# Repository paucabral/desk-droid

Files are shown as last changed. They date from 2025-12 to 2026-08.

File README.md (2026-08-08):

# DeskDroid




> A compact, autonomous ESP32-S3 desktop companion robot featuring expressive OLED eyes, environmental telemetry, capacitive gesture controls, and a local web dashboard interface.

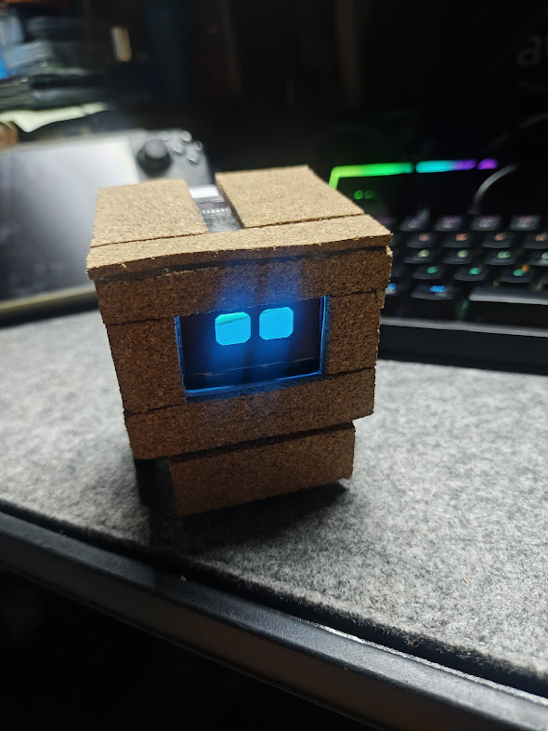
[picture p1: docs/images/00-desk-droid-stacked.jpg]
stacked


## Preview

This build uses PVC boards and Cork Sheets for the chassis, and pogo pin magnets for split chassis connectivity between the standalone base and the motor chassis.
| Parts | Preview |
| :--- | :--- |
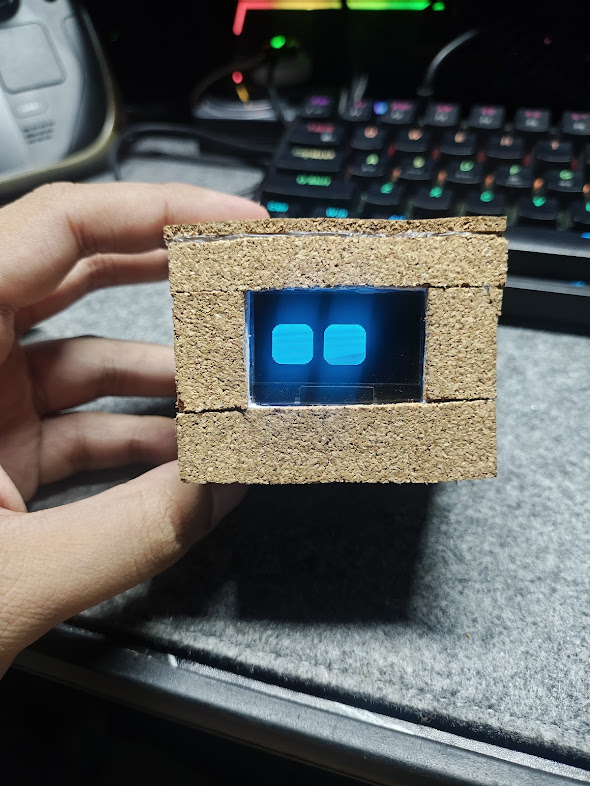
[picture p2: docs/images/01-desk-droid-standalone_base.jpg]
Standalone Base
| Standalone Base |  |
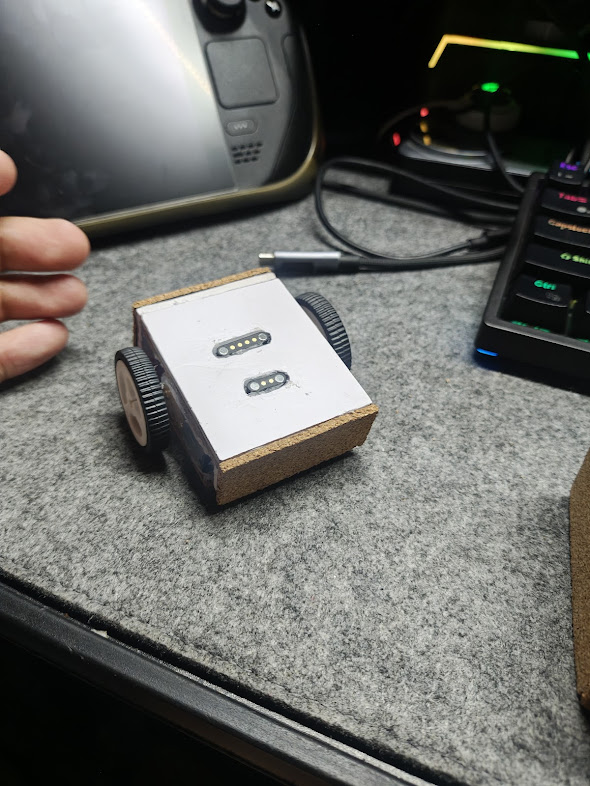
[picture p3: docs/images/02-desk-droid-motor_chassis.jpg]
Motor Chassis
| Motor Chassis |  |
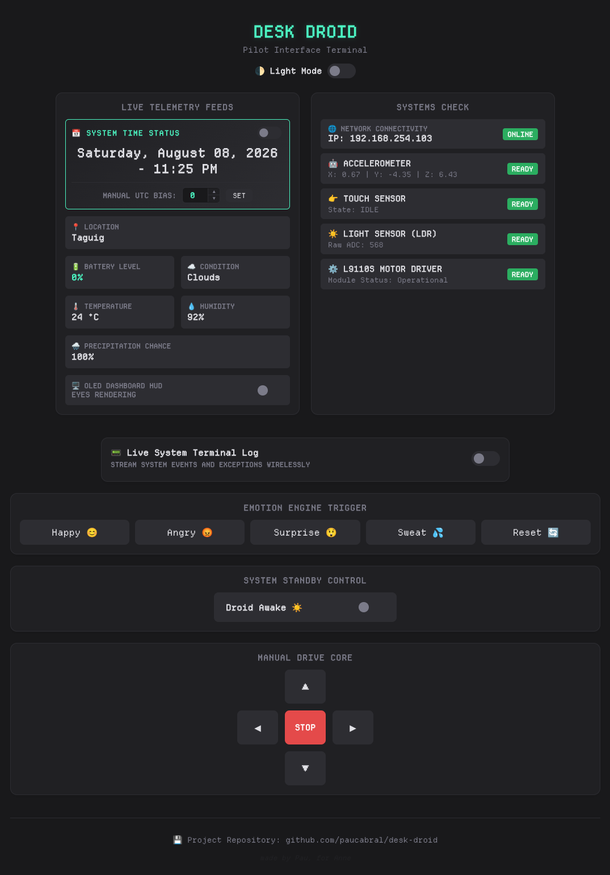
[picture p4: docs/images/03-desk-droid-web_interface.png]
Web Interface
| Web Interface |  |

## Key Features
- Expressive Eye Animations: Dynamic emotional states (Happy, Angry, Confused, Sweating, Tired) powered by FluxGarage_RoboEyes on a 1.3" OLED display.
- Interactive Touch Gestures: Single-point capacitive touch interface supporting multi-tier hold duration triggers (Happy reaction, Angry reaction, Dashboard overlay, and Deep Sleep power management).
- Local Web Dashboard & Remote Control: Built-in HTTP server hosting a responsive dashboard to drive locomotion, force emotional states, toggle military/standard time, view live sensor telemetry, and read streaming serial logs.
- Environmental & Motion Awareness:
  - ADXL345 Accelerometer: High-G shake detection and physics reaction loops.
  - TEMT600 Light Sensor: Ambient light detection for automatic screen dimming and night sleep mode.
  - OpenWeather API & NTP Synchronization: Automatic location, weather condition, temperature, humidity, and clock updates via Wi-Fi.
- Autonomous and Manual Navigation: Idle motion loops and manual navigation through the web dashboard when connected to the optional motor chassis.

## Parts and Dependencies

### 💿 Software
1. **Development Environment:** [Visual Studio Code](https://code.visualstudio.com/) with [PlatformIO](https://platformio.org/) Extension installed.
2. **Core Libraries:** (as seen in [lib/README.md](lib/README.md)):
    - Adafruit_GFX & Adafruit_SH110X (Display Driver)
    - Adafruit_ADXL345_U & Adafruit_Sensor (Accelerometer)
    - FluxGarage_RoboEyes (Eye Animations)
    - CuteBuzzerSounds (Audio Effects)
    - WiFiManager (Captive Portal Provisioning)
    - ArduinoJson (Web Telemetry Parsing)
3. **Cloud Services:** [OpenWeather API Key](https://openweathermap.org/api) (Free Tier)

### ⚙️ Hardware

| Category | Component | Specification |
| :--- | :--- | :--- |
| **Microcontroller** | ESP32-S3 SuperMini | Dual-core 240MHz, 2.4GHz Wi-Fi |
| **Display** | 1.3" OLED Display | SH1106G I2C (128x64 resolution) |
| **Sensors** | TEMT600 | Ambient Light Sensor |
| | ADXL345 | 3-Axis Digital Accelerometer |
| | TTP223 | Capacitive Touch Module |
| **Actuators** | G12 N20 DC Motors (Right Angled) | Dual Gear Motors w/ L9110S Driver |
| | Piezo Buzzer | Passive Buzzer for audio cues |
| **Power** | 3.7V LiPo Battery | Single-cell rechargeable battery |

## Project Structure
```
desk-droid/
├── fritzing/              # Circuit schematics and component models
│   ├── parts/             # Custom Fritzing component definitions
│   └── desk-droid.fzz     # Main project circuit schematic
├── include/               # System C++ header interfaces
│   ├── audio_system.h     # Audio player & buzzer API header
│   ├── config.h           # Hardware pinout & system threshold constants
│   ├── display_ui.h       # OLED screen & dashboard drawer functions
│   ├── motors.h           # L9110S motor direction state declarations
│   ├── network_system.h   # Web server, telemetry & API endpoints
│   └── power_system.h     # Power telemetry & deep sleep interface
├── lib/                   # Project dependencies & vendor libraries
│   ├── CuteBuzzerSounds/  # Passive buzzer sound effects library
│   └── RoboEyes/          # FluxGarage RoboEyes display animation engine
├── src/                   # Core software implementation
│   ├── audio_system.cpp   # Audio hardware routines
│   ├── dashboard.html     # Single-file Web UI dashboard (HTML/CSS/JS)
│   ├── display_ui.cpp     # OLED UI graphics rendering engine
│   ├── main.cpp           # Main lifecycle setup(), loop() & event handlers
│   ├── motors.cpp         # L9110S motor driver hardware implementations
│   ├── network_system.cpp # Web server routes & OpenWeather API fetchers
│   └── power_system.cpp   # Power telemetry & deep sleep implementation
├── platformio.ini         # PlatformIO build environment configuration
├── secrets.ini            # Private credentials file (Git ignored)
└── secrets.ini.example    # Configuration template for secrets
```

Note: `README.md` files in each directory for further details.

## Usage

### 🤖 Schematics
Follow the schematics as seen in [fritzing/desk-droid.fzz](fritzing/desk-droid.fzz). Use [Fritzing](https://fritzing.org/) and follow the instructions at [fritzing/README.md](fritzing/README.md) to import the parts.

### 🌐 Code: Building & Uploading
1. Clone the repository and open in VScode with PlatformIO extension installed.
2. Import the PlatformIO libraries listed in [lib/README.md](lib/README.md).
3. Create a `secrets.ini` file using [secrets.ini.example](secrets.ini.example) as reference, and place your [OpenWeather API key](https://openweathermap.org/api).
    ```ini
    [secrets]
    OPENWEATHER_API_KEY = your_openweather_api_key_here
    ```
4. Connect the microcontroller and select the proper port.
5. **Build** then **Upload** the project.

### 🛜 Initial Wi-Fi Setup
On first boot (or if saved Wi-Fi is unavailable), DeskDroid will create a Wi-Fi Access Point named Desk-Droid-Setup. Connect to this network on your smartphone or PC to enter your local Wi-Fi credentials via the captive portal. Once connected, DeskDroid will acquire an IP address and display it on-screen.

### 🎮 Interactive Controls & Touch Gestures

DeskDroid uses time-based hold durations on the **TTP223 Touch Sensor** to navigate modes:

| Duration | Action | Response |
| :--- | :--- | :--- |
| **0.3s – 0.9s** | Short Tap | **Happy Reaction:** Laugh animation, sound effect, and brief forward scoot. |
| **1.0s – 1.8s** | Medium Hold | **Angry Reaction:** Angry eyes, sound effect, and brief backward scoot. |
| **1.8s** | Long Hold | **Dashboard Toggle:** Opens environmental metrics & system status overlay. |
| **3.0s+** | Sustained Press | **Deep Sleep:** Plays shutdown chime, powers off OLED, and enters low-power sleep. |

### 🌐 Web Dashboard
Access the DeskDroid web control interface by navigating to http://<DROID_IP_ADDRESS> in any web browser. The following API endpoints are also available:
- /drive?dir=[forward|backward|left|right|stop]: Manual drive overrides.
- /emotion?type=[happy|angry|confused|sweat|default]: Force specific emotional animations.
- /telemetry: Fetches JSON data for battery, weather, location, time, and system states.
- /serial_data: Real-time web terminal stream for debugging logs without a USB connection.

## 🤖 AI Usage & Transparency Disclaimer
This repository was developed with assistance from Large Language Model (LLM) AI tools acting as a collaborative coding partner.
- Code Refactoring & Optimization: AI was used for low-level I2C multiplexing routines, non-blocking timer loops, and debugging embedded power/brownout issues.
- Documentation & Web Assets: Project documentation, README.md structural formatting, and initial HTML/CSS dashboard layouts were generated or refined using AI prompts.
- Hardware Validation: All electronic circuits, PCB component choices, physical pin allocations, and assembly were manually constructed, tested, and verified on physical hardware by the author.

---

*DeskDroid: Made by Pau, for Anne*

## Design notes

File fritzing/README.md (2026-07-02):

### Fritzing Files

This directory is intended for [Fritzing](https://fritzing.org/) parts and project files.

### Parts
Parts list directory (as imported in this repository):
- **ESP32-S3 SuperMini**
    - [💬 Forum Link](https://forum.fritzing.org/t/part-request-esp32-s3-supermini/22633/3)
    - [💾 Direct Download](https://forum.fritzing.org/uploads/short-url/of9Geqh2JwUCkv0tIVA6ZAqvkB.fzpz)
- **1.3 inch OLED 128x64 I2C**
    - [💬 Forum Link](https://forum.fritzing.org/t/oled-128x64-i2c-monochrome-display-ssd1306-created/1202)
    - [💾 Direct Download](https://forum.fritzing.org/uploads/default/original/1X/72f402789483e5047e79393485ef8bd9f9c0cb51.fzpz)
- **Passive Buzzer**
    - [💬 Forum Link](https://forum.fritzing.org/t/where-to-find-small-buzzer-in-fritzing/4843/3)
    - [💾 Direct Download](https://forum.fritzing.org/uploads/short-url/4nW0Ru7nvFcOlm5PVc3IXuMKVPB.fzpz)
- **Capacitive Touch Sensor**
    - [💬 Forum Link](https://forum.fritzing.org/t/ttp223b-module-alternative-design/11139/2)
    - [💾 Direct Download](https://forum.fritzing.org/uploads/short-url/6EryNAQ6wU4tDFa4MLlj1lODkUe.fzpz)
- **DHT11 Temperature and Humidity Sensor**
    - [💬 Forum Link](https://arduinomodules.info/download/ky-015-temperature-humidity-sensor-module-zip-file/)
    - [💾 Direct Download](https://arduinomodules.info/download/ky-015-temperature-humidity-sensor-module-zip-file/#unlock)
- **TEMT6000 Light Sensor**
    - [💬 Forum Link](https://forum.fritzing.org/t/temt6000-brick-download/20406/2)
    - [💾 Direct Download](https://forum.fritzing.org/uploads/short-url/kp9lpQa11v5nO44Q2Xz5W5kLW1z.fzpz)
- **MQ-135 Air Quality Sensor**
    - [💬 Forum Link](https://forum.fritzing.org/t/mq-135-gas-sensor-breakout-board/26152)
    - [💾 Direct Download](https://forum.fritzing.org/uploads/short-url/6SuZ75KSibpSUzOyTHRWeNgN6u2.fzpz)
**ADXL345 Accelerometer**
    - [💬 Forum Link](https://github.com/adafruit/Fritzing-Library/blob/master/parts/Adafruit%20ADXL345.fzpz)
    - [💾 Direct Download](blob:https://github.com/917bed7e-a063-43b2-9dba-4fa6b69fdde6)
**L9110 Motor Driver**
    - [💬 Forum Link](https://forum.fritzing.org/t/l9110-h-bridge-module/3110)
    - [💾 Direct Download](https://forum.fritzing.org/uploads/default/original/2X/4/487de66e80684795570d9a0d627331bf5953f003.fzpz)
**N20 Geared Motor**
    - [💬 Forum Link](https://forum.fritzing.org/t/anyone-got-an-n20-geared-mini-motor-fritzing-part/10380/11)
    - [💾 Direct Download](https://forum.fritzing.org/uploads/short-url/jln51m9ZQEeF1leAfTUMDkc4lj8.fzpz)

<!-- Template -->
<!-- **Part**
    - [💬 Forum Link]()
    - [💾 Direct Download]() -->

### Usage
1. Create a new bin named `desk-droid` inside inside Fritzing.
2. Import the parts inside the [parts/](parts/) library in the newly created `desk-droid` bin.
3. Open the `desk-droid.fzz` project.

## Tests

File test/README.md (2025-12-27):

# Tests

This directory is intended for PlatformIO Test Runner and project tests.

Unit Testing is a software testing method by which individual units of
source code, sets of one or more MCU program modules together with associated
control data, usage procedures, and operating procedures, are tested to
determine whether they are fit for use. Unit testing finds problems early
in the development cycle.

More information about PlatformIO Unit Testing:
- https://docs.platformio.org/en/latest/advanced/unit-testing/index.html

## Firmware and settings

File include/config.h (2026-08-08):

#pragma once

// OLED CONFIGURATION
#define OLED_I2C_ADDRESS        0x3c
#define OLED_SCL                13
#define OLED_SDA                12
#define OLED_SCREEN_WIDTH       128 
#define OLED_SCREEN_HEIGHT      64 
#define OLED_RESET              -1   

// BUZZER PIN
#define BUZZER_PIN              11

// TOUCH SENSOR PIN
#define TOUCH_PIN               10

// LIGHT SENSOR (LDR) CONFIGURATION
#define LDR_PIN                 8
#define LDR_THRESHOLD           200 

// ACCELEROMETER CONFIGURATION
#define ACCEL_SCL               7
#define ACCEL_SDA               6
#define SHAKE_THRESHOLD         15.0

// MOTOR CONFIGURATION (Dual H-Bridge e.g., L9110S / L298N)
#define MOTOR_IA1               3  // Left Motor Forward Control
#define MOTOR_IB1               2  // Left Motor Backward Control
#define MOTOR_IA2               5  // Right Motor Forward Control
#define MOTOR_IB2               4  // Right Motor Backward Control
#define MOTOR_MOVE_DURATION_MIN 250  // Minimum Interval between motor movements (in milliseconds)
#define MOTOR_MOVE_DURATION_MAX 500  // Maximum Interval between motor movements (in milliseconds)
#define MOTOR_MOVE_INTERVAL_MIN 5000  // Minimum Interval between motor movements (in milliseconds)
#define MOTOR_MOVE_INTERVAL_MAX 10000  // Maximum Interval between motor movements (in milliseconds)

// WIFI PORTAL CONFIGURATION
#define WIFI_AP_NAME             "Desk-Droid-Setup"
#define WIFI_CONNECT_TIMEOUT_SEC 10  // Seconds to try connecting to saved home Wi-Fi
#define WIFI_PORTAL_TIMEOUT_SEC  60  // Seconds the hotspot stays active before skipping to offline mode

// DASHBOARD CONFIGURATION
#define DASHBOARD_DURATION_MS    8000

// EVENT TRIGGERTS
#define TRIGGER_HAPPY_HOLD_MS    300   // 0.3s to 0.9s  = Happy
#define TRIGGER_ANGRY_HOLD_MS    1000  // 1.0s to 1.8s  = Angry
#define TRIGGER_DASHBOARD_MS     1800  // 1.8s          = Dashboard Opens
#define TRIGGER_SLEEP_MS         3000  // 3.0s          = Deep Sleep (Only 1.2s after Dashboard!)
#define DEBOUNCE_DELAY_MS        600   // 600ms dropout tolerance

// LIVE API CONFIGURATION
#define WEATHER_UPDATE_INTERVAL   900000  // Refresh every 15 minutes (in milliseconds)

// SHUTDOWN & SLEEP TRIGGERS
#define FREE_BATTERY_PIN         1     // Change this to your 1 remaining physical GPIO pin index!
#define TRIGGER_SLEEP_MS         10000  // Holding the touch pad for 10 full seconds triggers "Shutdown" Mode

// ADC CALIBRATION PROPERTIES
#define ADC_VREF_VOLTAGE         3.3   // ESP32-S3 internal operating logic voltage reference cap

// DYNAMIC SWEAT EMOTION CONFIGURATION
#define SWEAT_TEMP_THRESHOLD_C   30    // Temperature threshold to trigger sweat (Celsius)
#define SWEAT_ANIM_DURATION_MS   2000  // Duration of the brief transitional sweat animation (in ms)

// ─── LOCAL TIME CORE CONFIGURATION ───
#define DEFAULT_MILITARY_TIME    false  // Set to true for 24-Hour (19:25), false for 12-Hour (07:25 PM)
#define DEFAULT_TIMEZONE_OFFSET  28800
#define NTP_SERVER               "pool.ntp.org"

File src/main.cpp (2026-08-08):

#include <SPI.h>
#include <Wire.h>
#include <time.h>
#include <Adafruit_GFX.h>
#include <Adafruit_SH110X.h>
#include <Adafruit_Sensor.h>
#include <Adafruit_ADXL345_U.h>

#include <CuteBuzzerSounds.h>
#undef debug 

#include <WiFiManager.h> 
#include <ArduinoJson.h> 

// Modular System Interfaces
#include "config.h"
#include "display_ui.h"
#include "motors.h"
#include "audio_system.h"
#include "network_system.h"
#include "power_system.h"

#include "soc/soc.h"
#include "soc/rtc_cntl_reg.h"

// Instantiate Global Hardware Objects
Adafruit_SH1106G display = Adafruit_SH1106G(OLED_SCREEN_WIDTH, OLED_SCREEN_HEIGHT, &Wire1, OLED_RESET);
Adafruit_ADXL345_Unified accel = Adafruit_ADXL345_Unified(12345);

#undef DEFAULT 
#include <FluxGarage_RoboEyes.h>
RoboEyes<Adafruit_SH1106G> roboEyes(display); 

// Global Timers
unsigned long env_timer;           
unsigned long idle_timer;          
unsigned long next_idle_interval;  
unsigned long motor_stop_time = 0; 
unsigned long weather_timer = 0;   
unsigned long accel_timer = 0;

// Gesture & Page Management Timers
unsigned long touch_start_time = 0;
unsigned long dashboard_timeout = 0; 
unsigned long sweat_timeout = 0;     

// Global Web UI Intercept System Flags
bool web_control_active = false;
unsigned long web_mode_timeout = 0;
bool robot_sleeping = false;          

// Global States
float last_x = 0, last_y = 0, last_z = 0;
bool motor_running = false;
bool showing_dashboard = false;    
bool showing_pre_sweat = false;    
bool showing_post_sweat = false;   
bool accel_available = false;

// Live API Dynamic Data Registries
String live_location = "UNKNOWN";
String live_condition = "WAITING...";
String live_time_short = "--:--";
String live_time_long = "LOADING...";
bool live_use_military_time = DEFAULT_MILITARY_TIME;
int live_hour_offset = 0;
long live_timezone_offset_sec = DEFAULT_TIMEZONE_OFFSET;
int live_temp = 0;
int live_humidity = 0;
int live_rain_chance = 0;

// Dynamic Fuel Gauge Variable
int live_battery_percentage = 100;

// Raw Sensor Hardware Data Registries ---
int live_light_level = 0;
float live_accel_x = 0.0;
float live_accel_y = 0.0;
float live_accel_z = 0.0;
bool live_touch_active = false;

// --- LINKER INTEGRATION HOOK ---
// Connects the dual-channel USB/Web serial logger from network_system.cpp
extern void logTerminal(String msg);

void playEyeShutdownAnimation() {
  roboEyes.setMood(DEFAULT); roboEyes.close(); roboEyes.setPosition(S);
  unsigned long anim_start = millis();
  while (millis() - anim_start < 1000) { roboEyes.update(); delay(15); }
}

// Emotion matrix interface bridge execution vector for remote HTTP client requests
void forceWebEmotion(String type) {
  if (type == "happy") { 
    showing_pre_sweat = false; showing_post_sweat = false; roboEyes.setSweat(OFF);
    roboEyes.setMood(HAPPY); roboEyes.anim_laugh(); playSoundAsync(S_SUPER_HAPPY); 
  }
  else if (type == "angry") { 
    showing_pre_sweat = false; showing_post_sweat = false; roboEyes.setSweat(OFF);
    roboEyes.setMood(ANGRY); playSoundAsync(S_OHOOH); 
  }
  else if (type == "confused") { 
    showing_pre_sweat = false; showing_post_sweat = false; roboEyes.setSweat(OFF);
    roboEyes.setMood(TIRED); roboEyes.anim_confused(); playSoundAsync(S_SURPRISE); 
  }
  else if (type == "sweat") { 
    // Route web sweat straight to post-sweat state layout.
    // This runs the full animation sequence, but bypasses opening the OLED dashboard!
    showing_pre_sweat = false;
    showing_post_sweat = true; 
    sweat_timeout = millis() + SWEAT_ANIM_DURATION_MS; 
    roboEyes.setMood(TIRED); 
    roboEyes.setSweat(ON); 
    playSoundAsync(S_CUDDLY);
  }
  else { 
    showing_pre_sweat = false; showing_post_sweat = false; roboEyes.setSweat(OFF);
    roboEyes.setMood(DEFAULT); roboEyes.setPosition(DEFAULT); 
  }
}

void updateTimeStrings() {
  struct tm timeinfo;
  if (getLocalTime(&timeinfo)) {
    char bufShort[32];
    char bufLong[64];
    
    if (live_use_military_time) {
      strftime(bufShort, sizeof(bufShort), "%H:%M %m/%d", &timeinfo);         // "19:49 07/04"
      strftime(bufLong, sizeof(bufLong), "%A, %B %d, %Y - %H:%M", &timeinfo);   // "Saturday, July 04, 2026 - 19:49"
    } else {
      strftime(bufShort, sizeof(bufShort), "%I:%M%p %m/%d", &timeinfo);       // "07:49PM 07/04"
      strftime(bufLong, sizeof(bufLong), "%A, %B %d, %Y - %I:%M %p", &timeinfo); // "Saturday, July 04, 2026 - 07:49 PM"
    }
    live_time_short = String(bufShort);
    live_time_long = String(bufLong);
  } else {
    live_time_short = "SYNCING";
    live_time_long = "CONNECTING TO TIME POOL SERVER...";
  }
}

void setup() {
  // ─── DISABLE BROWNOUT DETECTOR AT BOOT ───
  WRITE_PERI_REG(RTC_CNTL_BROWN_OUT_REG, 0);

  initMotors();

  // Divert early boot tracking messages through the unified logging portal
  logTerminal(F("=== DROID OS BOOTING ==="));
  delay(1000); 

  Wire1.begin(OLED_SDA, OLED_SCL);
  display.begin(OLED_I2C_ADDRESS, true);
  drawChecklist(" ", " ", " ", " ", " ", "INITIALIZING...");
  delay(800); 

  Wire.begin(ACCEL_SDA, ACCEL_SCL);
  if(!accel.begin()) {
    drawChecklist("X", " ", " ", " ", " ", "ACCEL BYPASSED");
    accel_available = false; delay(1500);
  } else {
    accel.setRange(ADXL345_RANGE_4_G);
    drawChecklist("*", " ", " ", " ", " ", "   TESTING...");
    accel_available = true; delay(500);
  }

  pinMode(TOUCH_PIN, INPUT);
  drawChecklist("*", "*", " ", " ", " ", "   TESTING..."); delay(500);
  pinMode(LDR_PIN, INPUT);
  drawChecklist("*", "*", "*", " ", " ", "   TESTING..."); delay(500);
  cute.init(BUZZER_PIN);
  drawChecklist("*", "*", "*", "*", " ", "   TESTING..."); delay(500);

  initAudioSystem();
  drawChecklist("*", "*", "*", "*", "*", "       READY!");
  cute.play(S_CONNECTION); delay(1000); 

  drawWifiScreen("NETWORK CHECK", "SEARCHING...", "Checking memory for\nsaved network connections");
  
  WiFiManager wm;
  wm.setAPCallback(configModeCallback);
  wm.setConnectTimeout(WIFI_CONNECT_TIMEOUT_SEC); 
  wm.setConfigPortalTimeout(WIFI_PORTAL_TIMEOUT_SEC);

  if (wm.autoConnect(WIFI_AP_NAME)) {
    WiFi.setTxPower(WIFI_POWER_11dBm); // Cuts peak current spike significantly!

    String ipMsg = "IP: " + WiFi.localIP().toString();
    drawWifiScreen("NETWORK CHECK", "ONLINE [OK]", ipMsg.c_str());
    live_location = "LOCALIZING..."; 
    // Initialize native OS clock to UTC+8 layout instantly before hitting APIs
    configTime(live_timezone_offset_sec, 0, NTP_SERVER);
    fetchLocationAndWeather(); 
    initWebServer();
  } else {
    drawWifiScreen("NETWORK CHECK", "OFFLINE MODE", "No connection found.\nBypassing network boot.");
    live_location = "OFFLINE"; live_condition = "N/A";
  }
  delay(2500);

  drawSplashArt(); delay(3000); 
  for(int i = 0; i < 3; i++) {
    display.clearDisplay(); display.display(); delay(40);
    drawSplashArt(); delay(60);
  }
  playSoundAsync(S_HAPPY_SHORT);

  roboEyes.begin(OLED_SCREEN_WIDTH, OLED_SCREEN_HEIGHT, 100); 
  roboEyes.setAutoblinker(ON, 3, 2);
  roboEyes.setIdleMode(ON, 2, 2);

  env_timer = millis(); idle_timer = millis(); weather_timer = millis(); accel_timer = millis();
  next_idle_interval = random(MOTOR_MOVE_INTERVAL_MIN, MOTOR_MOVE_INTERVAL_MAX); 
  randomSeed(analogRead(LDR_PIN)); 
}

void loop() {
  if (WiFi.status() == WL_CONNECTED) {
    handleWebClient();
    if (web_control_active && (millis() >= web_mode_timeout)) {
      web_control_active = false;
      logTerminal(F("[WEB-SERVER] Web timeout expired. Returning to autonomous navigation."));
    }
  }

  // --- Page Layout Router Engine ---
  if (robot_sleeping) {
    roboEyes.close();
    roboEyes.update();
  } 
  else if (showing_dashboard) {
    if (millis() >= dashboard_timeout) {
      showing_dashboard = false; 
      if (live_temp >= SWEAT_TEMP_THRESHOLD_C) {
        showing_post_sweat = true; sweat_timeout = millis() + SWEAT_ANIM_DURATION_MS;
        roboEyes.setMood(TIRED); roboEyes.setSweat(ON);
      } else {
        roboEyes.setMood(DEFAULT); roboEyes.setPosition(DEFAULT);
      }
    } else {
      String ipStr = (WiFi.status() == WL_CONNECTED) ? WiFi.localIP().toString() : "OFFLINE";
      String locationWithClock = live_location + " (" + live_time_short + ")";
      drawDashboard(live_condition.c_str(), live_temp, live_humidity, live_rain_chance, ipStr.c_str(), live_battery_percentage, live_location.c_str(), live_time_short.c_str());
    }
  } 
  else if (showing_pre_sweat) {
    if (millis() >= sweat_timeout) {
      showing_pre_sweat = false; roboEyes.setSweat(OFF); playSoundAsync(S_CUDDLY);
      showing_dashboard = true; dashboard_timeout = millis() + DASHBOARD_DURATION_MS;
    } else { roboEyes.update(); }
  } 
  else if (showing_post_sweat) {
    if (millis() >= sweat_timeout) {
      showing_post_sweat = false; roboEyes.setSweat(OFF);
      roboEyes.setMood(DEFAULT); roboEyes.setPosition(DEFAULT); playSoundAsync(S_CUDDLY);
    } else { roboEyes.update(); }
  } 
  else { roboEyes.update(); }

  // --- Real-Time Safety Intercept Flags ---
  if (!web_control_active && motor_running && millis() >= motor_stop_time) {
    moveDroid(STOP); motor_running = false;
  }

  if (WiFi.status() == WL_CONNECTED && (millis() - weather_timer >= WEATHER_UPDATE_INTERVAL)) {
    weather_timer = millis(); fetchLocationAndWeather(); 
  }

  // --- NOISE-BRIDGED ASYNCHRONOUS TOUCH SAMPLING ENGINE ---
  int rawTouchReading = digitalRead(TOUCH_PIN);
  live_touch_active = (rawTouchReading == HIGH);
  static bool is_pressing = false;
  static unsigned long true_touch_start = 0;
  static unsigned long last_active_high_time = 0;
  static bool dashboard_triggered_this_press = false;

  if (rawTouchReading == HIGH) {
    if (!is_pressing) {
      is_pressing = true; 
      true_touch_start = millis(); 
      dashboard_triggered_this_press = false;
      
      if (robot_sleeping) { 
        robot_sleeping = false; 
        roboEyes.open(); 
        playSoundAsync(S_CONNECTION); 
        logTerminal(F("[HARDWARE] Touch detected! Waking up..."));
      }
    }
    last_active_high_time = millis(); 
  }

  if (is_pressing) {
    unsigned long current_hold_duration = millis() - true_touch_start;

    // Trigger 1: Dashboard View (1.8 Seconds)
    if (!dashboard_triggered_this_press && current_hold_duration >= TRIGGER_DASHBOARD_MS && current_hold_duration < TRIGGER_SLEEP_MS) {
      dashboard_triggered_this_press = true;
      playSoundAsync(S_BUTTON_PUSHED); // Audio hint: Keep holding for Sleep!
      
      if (live_temp >= SWEAT_TEMP_THRESHOLD_C) {
        showing_pre_sweat = true; 
        sweat_timeout = millis() + SWEAT_ANIM_DURATION_MS;
        roboEyes.setMood(TIRED); 
        roboEyes.setSweat(ON);
      } else {
        showing_dashboard = true; 
        dashboard_timeout = millis() + DASHBOARD_DURATION_MS; 
      }
    }

    // Trigger 2: Deep Sleep (3.0 Seconds)
    if (current_hold_duration >= TRIGGER_SLEEP_MS) {
      is_pressing = false; 
      playSoundAsync(S_DISCONNECTION);
      delay(200); // Allow buzzer tone to finish playing before shutdown
      enterSystemDeepSleep(); 
    }

    // Trigger 3: Finger Release Evaluator
    // Dynamic dropout allowance: If Dashboard already opened, allow a wider 750ms dropout window
    unsigned long max_allowed_dropout = dashboard_triggered_this_press ? 750 : 500;

    if (rawTouchReading == LOW && (millis() - last_active_high_time > max_allowed_dropout)) {
      is_pressing = false; // Officially end press state
      
      if (!dashboard_triggered_this_press) {
        unsigned long total_hold = last_active_high_time - true_touch_start;
        
        if (total_hold >= TRIGGER_HAPPY_HOLD_MS && total_hold < TRIGGER_ANGRY_HOLD_MS) {
          if (!showing_dashboard && !showing_pre_sweat && !showing_post_sweat) {
            roboEyes.setMood(HAPPY); 
            roboEyes.anim_laugh(); 
            playSoundAsync(S_SUPER_HAPPY); 
            moveDroid(FORWARD); 
            motor_stop_time = millis() + 150; 
            motor_running = true;
          }
        }
        else if (total_hold >= TRIGGER_ANGRY_HOLD_MS && total_hold < TRIGGER_DASHBOARD_MS) {
          if (!showing_dashboard && !showing_pre_sweat && !showing_post_sweat) {
            roboEyes.setMood(ANGRY); 
            playSoundAsync(S_OHOOH); 
            moveDroid(BACKWARD); 
            motor_stop_time = millis() + 300; 
            motor_running = true;
          }
        }
      }
    }
  }

  // --- Throttled Accelerometer Sampling Loop ---
  if (!robot_sleeping && accel_available && (millis() - accel_timer >= 25)) { 
    accel_timer = millis();
    sensors_event_t event; accel.getEvent(&event);

    // Update web diagnostic registries
    live_accel_x = event.acceleration.x;
    live_accel_y = event.acceleration.y;
    live_accel_z = event.acceleration.z;

    float delta_x = abs(event.acceleration.x - last_x);
    float delta_y = abs(event.acceleration.y - last_y); 
    float delta_z = abs(event.acceleration.z - last_z);
    last_x = event.acceleration.x; last_y = event.acceleration.y; last_z = event.acceleration.z;

    // LOG MODIFICATION: Intercept high-G threshold physics triggers
    if (delta_x > SHAKE_THRESHOLD || delta_y > SHAKE_THRESHOLD || delta_z > SHAKE_THRESHOLD) {
      if (!showing_dashboard && !showing_pre_sweat && !showing_post_sweat) {
        roboEyes.setMood(TIRED); roboEyes.anim_confused();
      }
      playSoundAsync(S_SURPRISE); 
      logTerminal(F("[ALERT] High G-force threshold breached! Droid is shaking."));
    }
  }

  // --- TIMER 1: Environmental Sampling & Battery Updates ---
  if (millis() - env_timer >= 1000) {
    env_timer = millis(); 
    updateBatteryTelemetry();

    updateBatteryTelemetry();

    // Regenerate active strings via native OS engine check
    updateTimeStrings();

    if (!robot_sleeping) { 
      int light_level = analogRead(LDR_PIN);
      live_light_level = light_level;
      if (light_level < LDR_THRESHOLD) {
        if (!showing_dashboard && !showing_pre_sweat && !showing_post_sweat) {
          roboEyes.close(); roboEyes.setPosition(S);
        }
        if (motor_running) { moveDroid(STOP); motor_running = false; }
      } else {
        if (!showing_dashboard && !showing_pre_sweat && !showing_post_sweat) { roboEyes.open(); }
      }
    }
  }

  // --- TIMER 2: Randomized Idle Movement ---
  if (!web_control_active && !robot_sleeping && (millis() - idle_timer >= next_idle_interval)) {
    idle_timer = millis(); 
    if (!showing_dashboard && !showing_pre_sweat && !showing_post_sweat) {
      roboEyes.setMood(DEFAULT); roboEyes.setPosition(DEFAULT); 
    }

    int current_light = analogRead(LDR_PIN);
    if (current_light >= LDR_THRESHOLD && !showing_dashboard && !showing_pre_sweat && !showing_post_sweat) {
      
      // LOG MODIFICATION: Track independent locomotion events automatically
      if (random(100) < 40) {
        DroidMovement options[] = {FORWARD, BACKWARD, TURN_LEFT, TURN_RIGHT};
        int choice = random(0, 4);
        moveDroid(options[choice]);
        
        logTerminal("[AUTONOMOUS] Internal AI triggered movement index: " + String(choice));
        
        motor_stop_time = millis() + random(MOTOR_MOVE_DURATION_MIN, MOTOR_MOVE_DURATION_MAX); 
        motor_running = true;
      }
    }
    next_idle_interval = random(MOTOR_MOVE_INTERVAL_MIN, MOTOR_MOVE_INTERVAL_MAX); 
  }
}

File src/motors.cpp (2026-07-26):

#include <Arduino.h>
#include "motors.h"
#include "config.h"

// Set up motor pins as outputs
void initMotors() {
  pinMode(MOTOR_IA1, OUTPUT);
  pinMode(MOTOR_IB1, OUTPUT);
  pinMode(MOTOR_IA2, OUTPUT);
  pinMode(MOTOR_IB2, OUTPUT);
  
  // Ensure droid starts completely still
  moveDroid(STOP);
}

// Single handler function that accepts the movement argument
void moveDroid(DroidMovement movement) {
  switch (movement) {
    case FORWARD:
      digitalWrite(MOTOR_IA1, LOW);
      digitalWrite(MOTOR_IB1, HIGH);
      digitalWrite(MOTOR_IA2, HIGH);
      digitalWrite(MOTOR_IB2, LOW);
      break;

    case BACKWARD:
      digitalWrite(MOTOR_IA1, HIGH);
      digitalWrite(MOTOR_IB1, LOW);
      digitalWrite(MOTOR_IA2, LOW);
      digitalWrite(MOTOR_IB2, HIGH);
      break;

    case TURN_LEFT:
      digitalWrite(MOTOR_IA1, HIGH);
      digitalWrite(MOTOR_IB1, LOW);
      digitalWrite(MOTOR_IA2, HIGH);
      digitalWrite(MOTOR_IB2, LOW);
      break;

    case TURN_RIGHT:
      digitalWrite(MOTOR_IA1, LOW);
      digitalWrite(MOTOR_IB1, HIGH);
      digitalWrite(MOTOR_IA2, LOW);
      digitalWrite(MOTOR_IB2, HIGH);
      break;

    case STOP:
    default:
      // All pins LOW cuts power to the motors
      digitalWrite(MOTOR_IA1, LOW);
      digitalWrite(MOTOR_IB1, LOW);
      digitalWrite(MOTOR_IA2, LOW);
      digitalWrite(MOTOR_IB2, LOW);
      break;
  }
}

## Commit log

2025-12-27 feat: initiate fritzing schematics
    [desk-droid.fzz]
2025-12-27 feat: imported touch sensor schematics and preliminary test code
    [desk-droid.fzz]
2025-12-27 feat: Update touch sensor fritzing schematics
    [desk-droid.fzz]
2025-12-27 chore: Add preliminary schematics documentation
2026-01-01 feat: Add schematics and references for DHT11
    [desk-droid.fzz]
2026-01-01 feat: Add light sensor lib documentations
2026-01-01 feat: Add preliminary photosensor schematics
    [desk-droid.fzz]
2026-01-01 feat: Add photosensor code and todo items
    [desk-droid.fzz]
2026-01-06 feat: Add preliminary schematics and code for MQ-135 sensor
    [desk-droid.fzz]
2026-07-01 chore(docs): remove air quality sensor and temperature/humidity sensor for now.
    [desk-droid.fzz]
2026-07-01 feat: remove air quality sensor and temperature/humidity sensor functionalties.
2026-07-01 fix: simplify logic from upon removal of sensors
    [desk-droid.fzz]
2026-07-01 fix: fix animation timing and sleep behavior
    [main.cpp]
2026-07-01 chore: removing commented initial inclusion of motion sensor
2026-07-01 feat: add accelerometer parts
    [desk-droid.fzz]
2026-07-01 feat: add preliminary code for accelerometer, using i2c bus
2026-07-01 feat: manual implementation test for accelerometer
    [desk-droid.fzz]
2026-07-01 feat: transition accelerometer implem to library based
2026-07-02 feat: add motor and motor driver parts
    [desk-droid.fzz]
2026-07-02 feat: readd Serial monitors and added test motor run codes
2026-07-02 feat: add motor movement controls
2026-07-02 chore: move parameters for motor movements into config
2026-07-02 feat: add motor driver in system check
2026-07-02 chore: update diagram wiring for motors
    [desk-droid.fzz]
2026-07-02 chore: added motors in the wiring diagram
    [desk-droid.fzz]
2026-07-03 fix: remove redundant constant variable
    [config.h]
2026-07-03 feat: add deep sleep and battery measurement
2026-07-03 feat: improve sleep state animation
    [desk-droid.fzz]
2026-07-03 feat: update circuit with voltage divider for battery measure
    [desk-droid.fzz]
2026-07-03 feat: updated power lines for motor driver
    [desk-droid.fzz]
2026-07-03 chore: add placeholder for battery in docs
2026-07-04 chore: lib structure fix and main.cpp optimization
    [main.cpp, power_system.cpp]
2026-07-04 feat: add fail-safe routing for accelerometer
    [main.cpp]
2026-07-04 feat: revamp web ui
    [desk-droid.fzz]
2026-07-04 feat: include polling for sensors telemetry data in web ui
2026-07-04 feat: implemented motor detection for separate chasis implementation
2026-07-05 feat: improved parts in fritzing for accuracy
    [desk-droid.fzz]
2026-07-07 feat: add preliminary protoboard design
    [desk-droid.fzz]
2026-07-12 fix: add resistor to fix chassis detection status
    [desk-droid.fzz]
2026-07-12 feat: add pogo pins reprepsentation in protoboard schematic
    [desk-droid.fzz]
2026-07-12 fix: restore working fritzing file
    [desk-droid.fzz]
2026-07-12 feat: add jst pin representation for battery connector
    [desk-droid.fzz]
2026-07-26 fix: update motor directions
    [motors.cpp]
2026-08-08 fix: adjust boot duration splash
    [main.cpp]
2026-08-08 feat: add battery optimization, remove brownout detector
    [main.cpp]
2026-08-08 feat: initialize motor pins early
2026-08-08 fix: remove chassis detection
    [main.cpp]
2026-08-08 fix: adjust touch thresholds
    [config.h, main.cpp]
